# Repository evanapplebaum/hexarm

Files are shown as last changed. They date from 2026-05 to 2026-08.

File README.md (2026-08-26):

# Hexarm




A custom anthropomorphic 6-DOF leader-follower robotic arm system roughly based on the open-source [SO-100](https://github.com/TheRobotStudio/SO-ARM100) design. Built for hands-on experience in mechanical design, embedded systems, and robot teleoperation, with imitation learning via the [LeRobot](https://github.com/huggingface/lerobot) framework.

> **Status:** ✅ Core pipeline complete. Both arms were built, calibrated, and made to teleoperate end-to-end. An ACT policy trained on a 50-episode pick-and-place dataset was run autonomously on the physical follower arm via a dead-man's-switch-gated control loop. Full session-by-session history lives in [docs/context.md](docs/context.md).

---

## Demo

<p align="center">
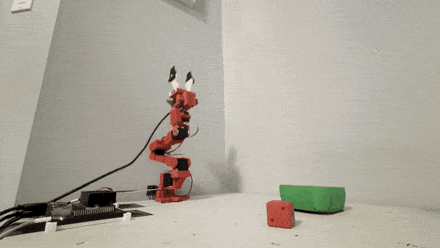
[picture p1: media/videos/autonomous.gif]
ACT policy running autonomously on the follower arm
  
</p>

**Autonomous policy.** An ACT policy trained on 50 teleoperated demonstrations, running
on the follower arm with no human input: approach, grasp, transport, release. Clip is
1.25× real time.

<p align="center">
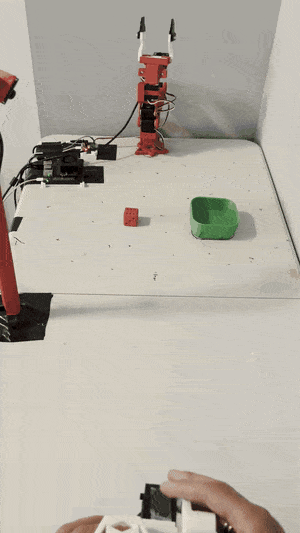
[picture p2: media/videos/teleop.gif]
Teleoperation: leader arm driven by hand, follower mirroring
  
</p>

**Teleoperation.** The leader arm (bottom) is backdriven by hand; the follower (top)
mirrors it at 50 Hz over a single half-duplex servo bus. This is how the training
demonstrations were recorded.

---

## Overview

| Property | Value |
|---|---|
| Configuration | Leader-follower (2 arms) |
| Degrees of Freedom | 6 per arm (5 + gripper) |
| Actuators | FEETECH STS3215 (6× per arm, 12 total) |
| Servo Driver | Waveshare Bus Servo Adapter (A) — half-duplex TTL, USB host |
| Compute | NVIDIA Jetson Orin Nano Super (JetPack 7.2, Ubuntu 24.04) |
| Bus interface | USB CDC-ACM on `/dev/ttyACM0` at 1 Mbps |
| Bus topology | Single bus — both arms (follower IDs 1–6, leader IDs 7–12) |
| Framework | [LeRobot](https://github.com/huggingface/lerobot) (`feetech` extra, editable install) |
| CAD Tool | [Onshape](https://cad.onshape.com) (public) |
| Reach | 433 mm |
| Payload | 1.2 kg @ worst case scenario (maximum reach) |

---

### CAD

| Leader | Follower |
|---|---|
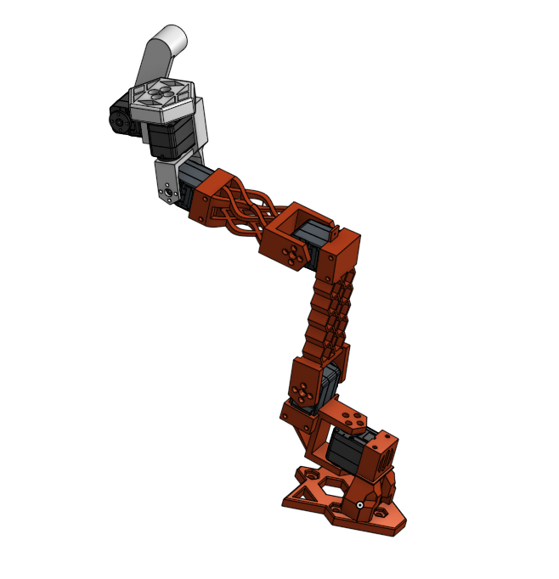
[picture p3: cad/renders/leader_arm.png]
Leader arm CAD assembly
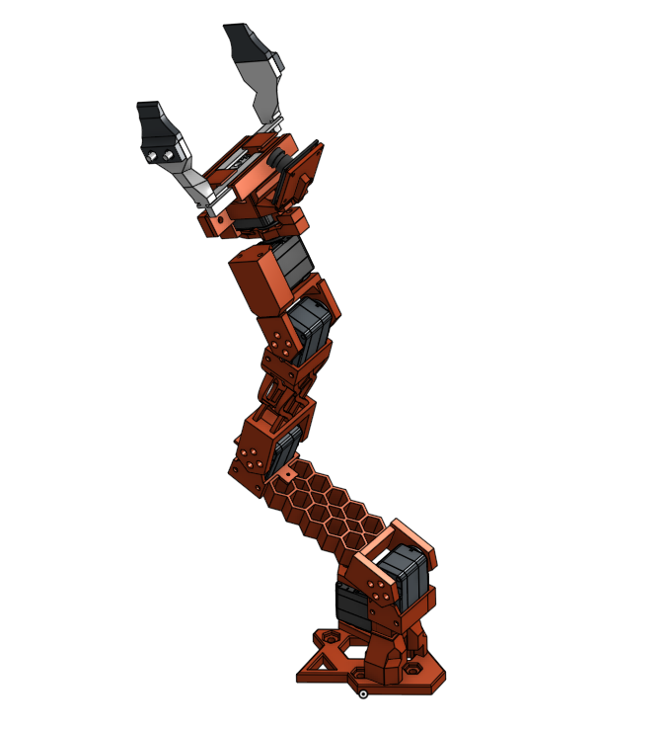
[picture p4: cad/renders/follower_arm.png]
Follower arm CAD assembly
|  |  |

*CAD renders (Onshape, 2026-08-09) of the finished leader and follower arm assemblies.*

### Hardware Photos

<table>
<tr>
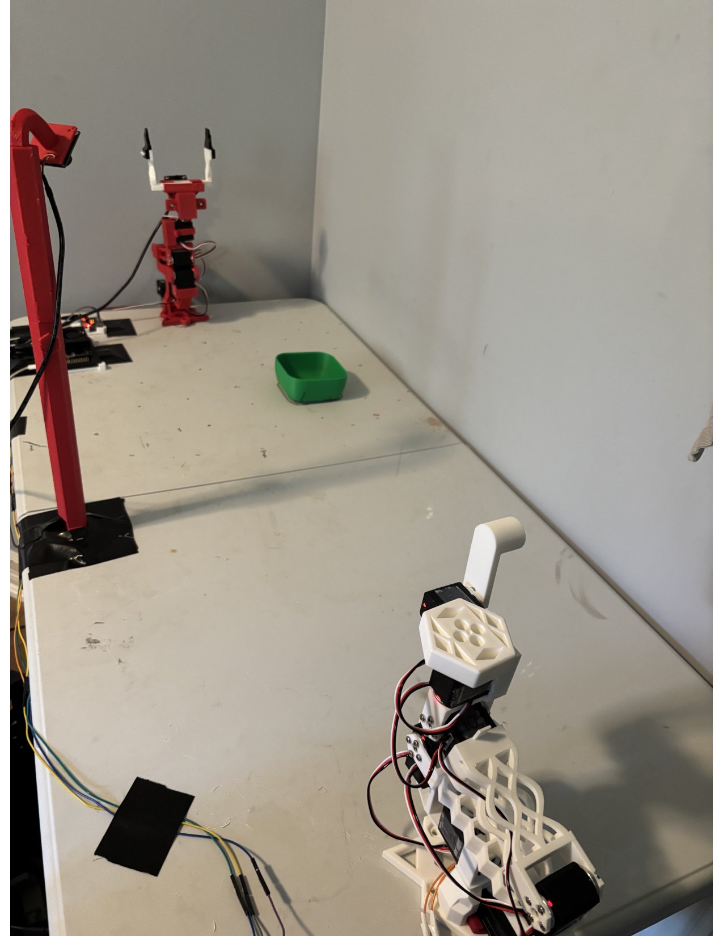
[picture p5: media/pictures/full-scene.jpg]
<td align="center"><br>Full workspace scene</td>
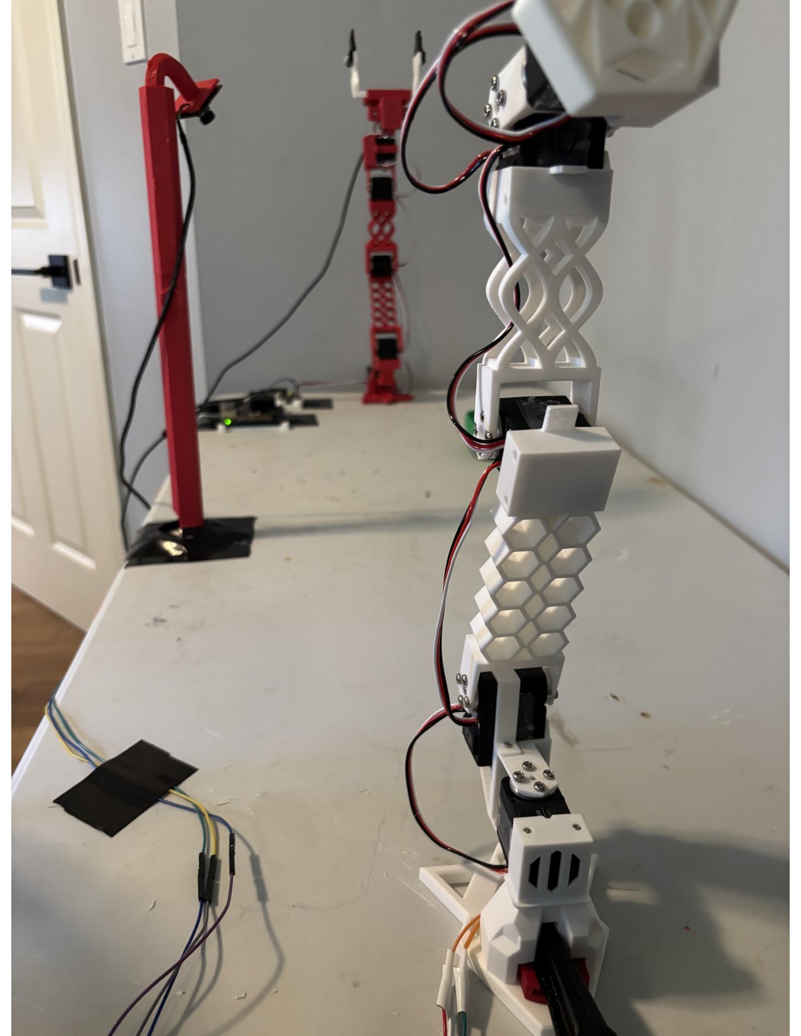
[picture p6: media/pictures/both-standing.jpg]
<td align="center"><br>Both arms</td>
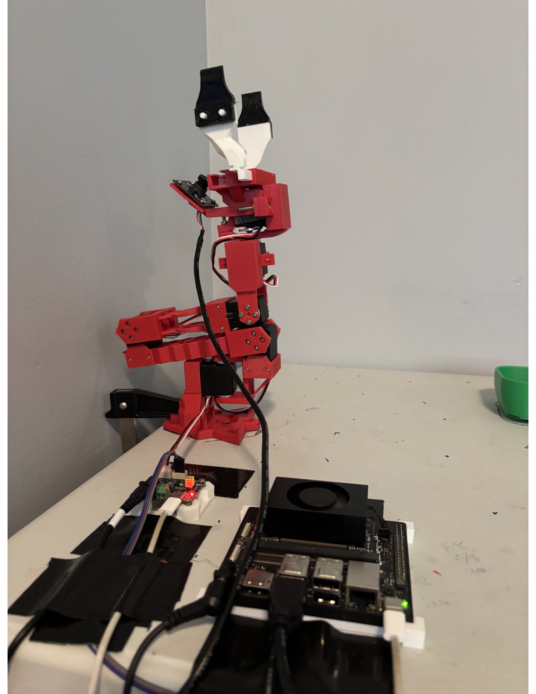
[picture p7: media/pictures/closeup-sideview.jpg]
<td align="center"><br>Side view close-up</td>
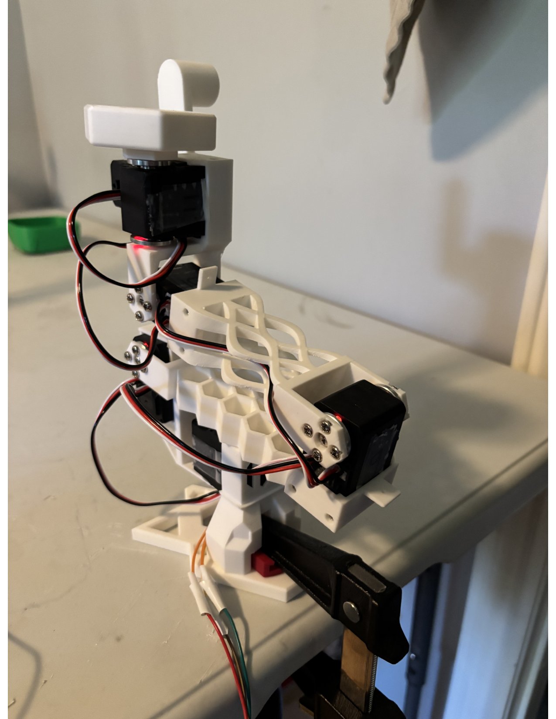
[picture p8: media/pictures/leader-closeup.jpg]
<td align="center"><br>Leader close-up</td>
</tr>
<tr>
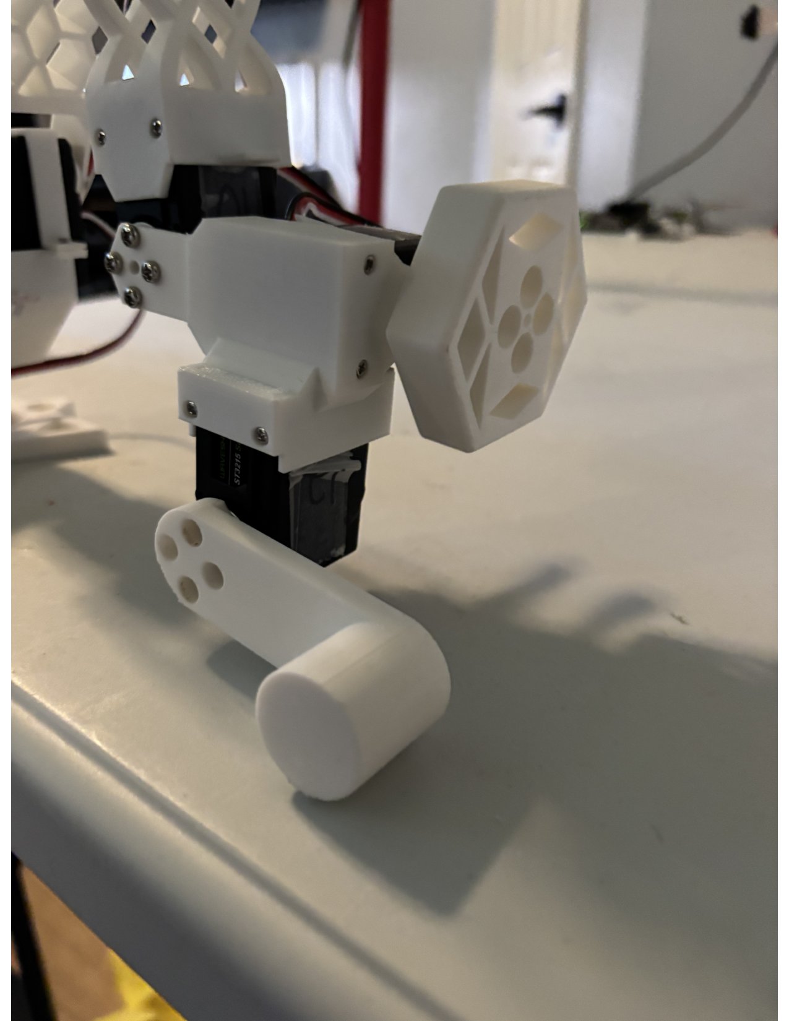
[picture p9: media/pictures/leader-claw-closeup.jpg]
<td align="center"><br>Leader claw close-up</td>
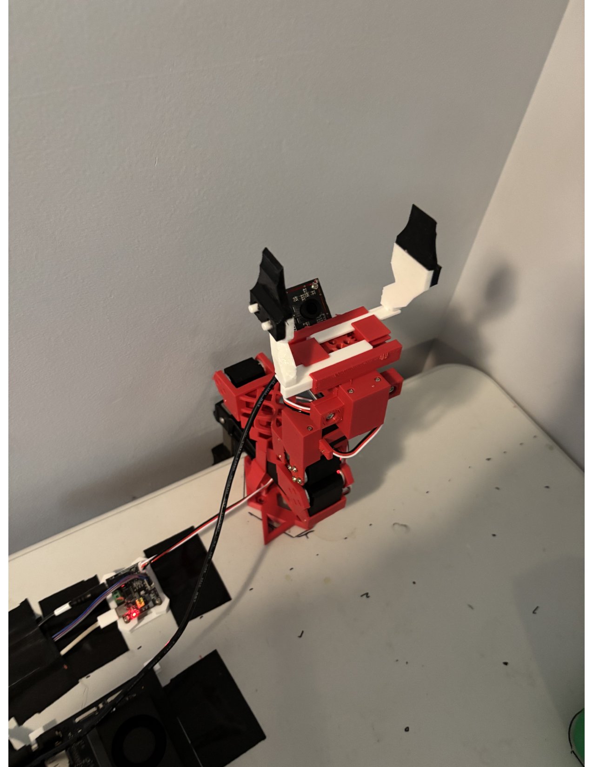
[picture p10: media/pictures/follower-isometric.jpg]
<td align="center"><br>Follower isometric</td>
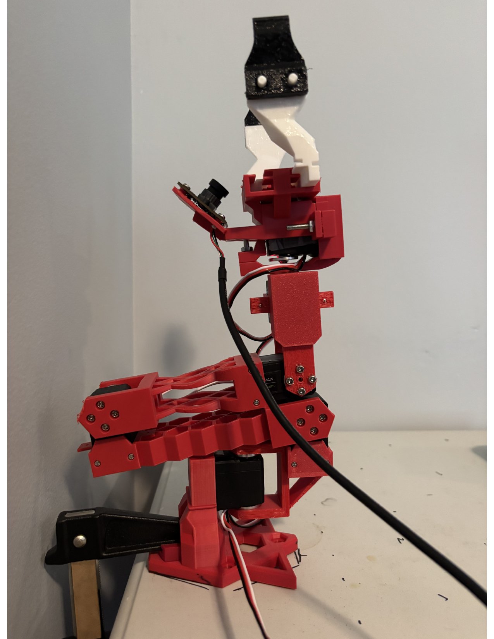
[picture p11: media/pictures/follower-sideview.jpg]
<td align="center"><br>Follower side view</td>
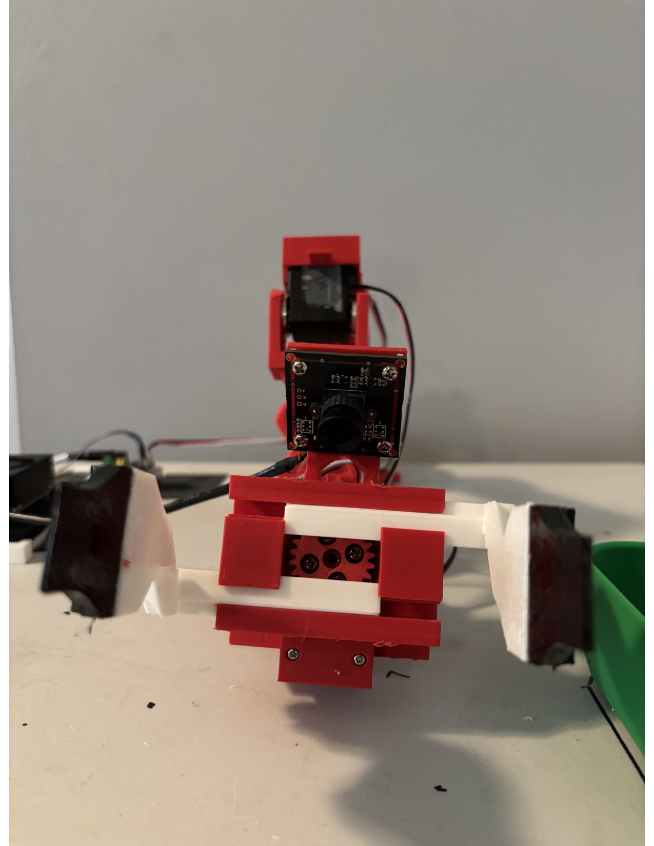
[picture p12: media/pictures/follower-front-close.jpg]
<td align="center"><br>Follower front close-up</td>
</tr>
<tr>
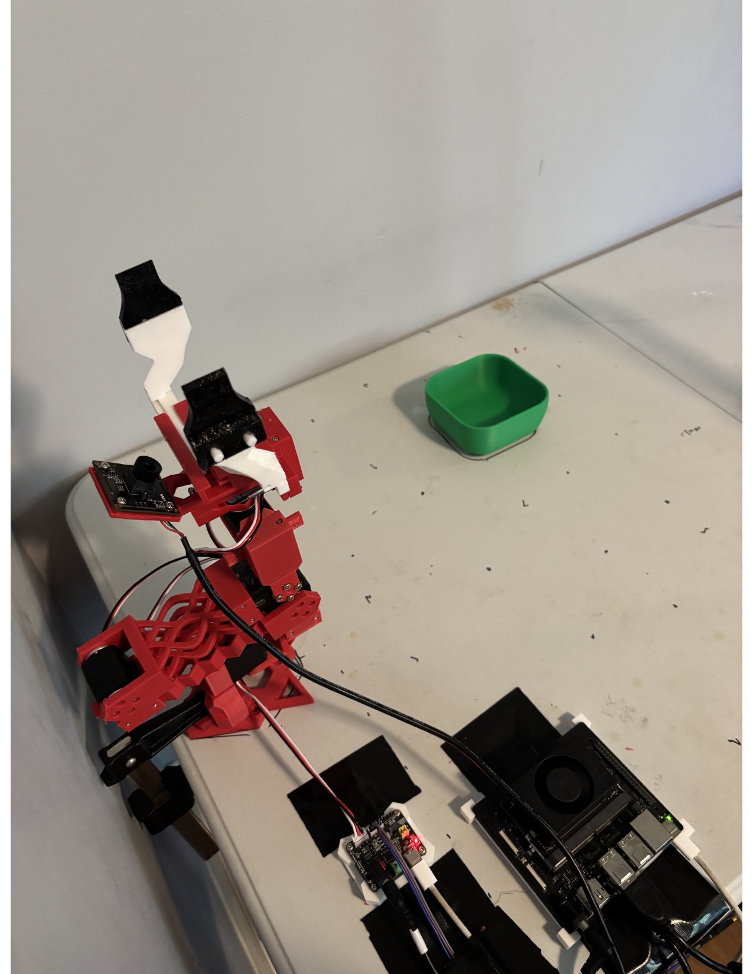
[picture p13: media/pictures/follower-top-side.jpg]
<td align="center"><br>Follower top/side view</td>
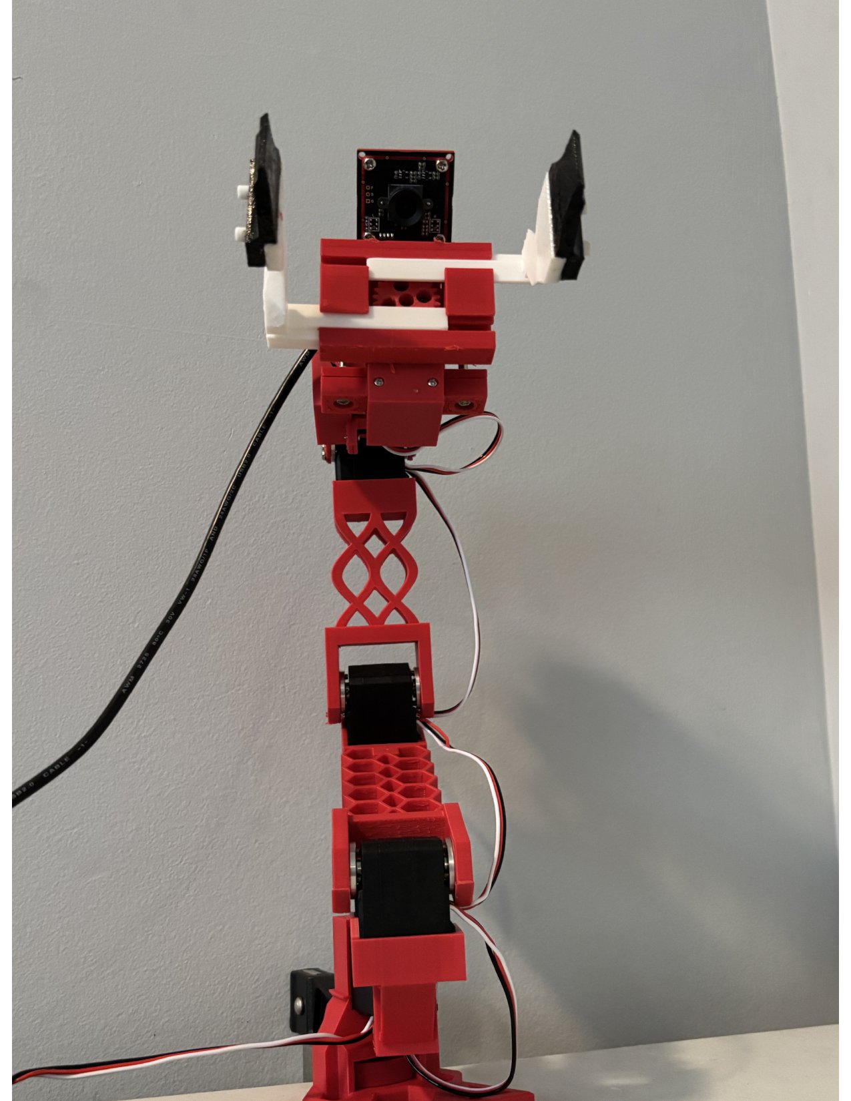
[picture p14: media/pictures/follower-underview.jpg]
<td align="center"><br>Follower underside</td>
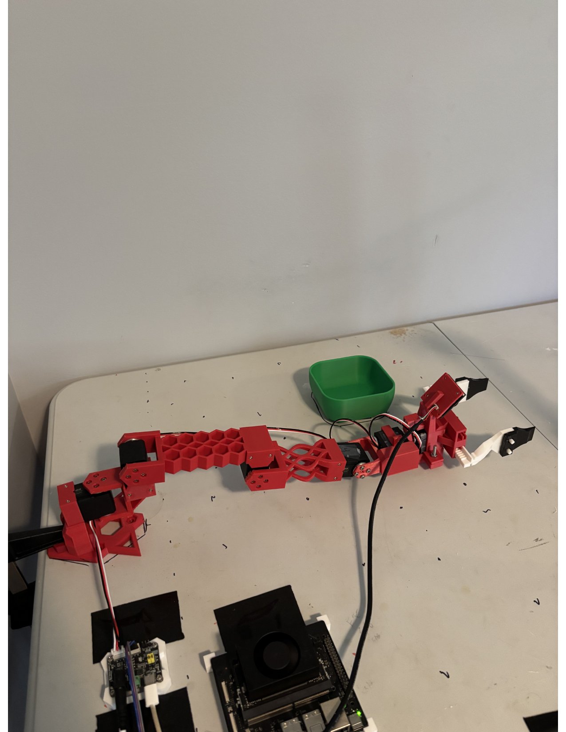
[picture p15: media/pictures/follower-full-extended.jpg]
<td align="center"><br>Follower fully extended</td>
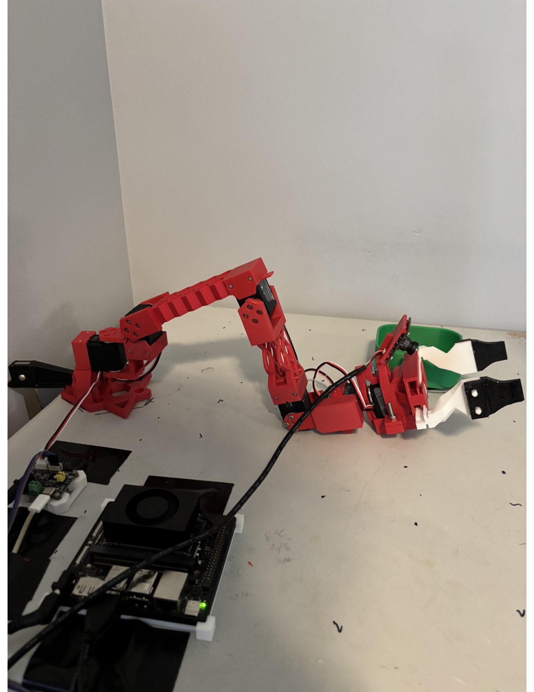
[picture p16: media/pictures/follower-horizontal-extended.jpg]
<td align="center"><br>Follower horizontal reach</td>
</tr>
<tr>
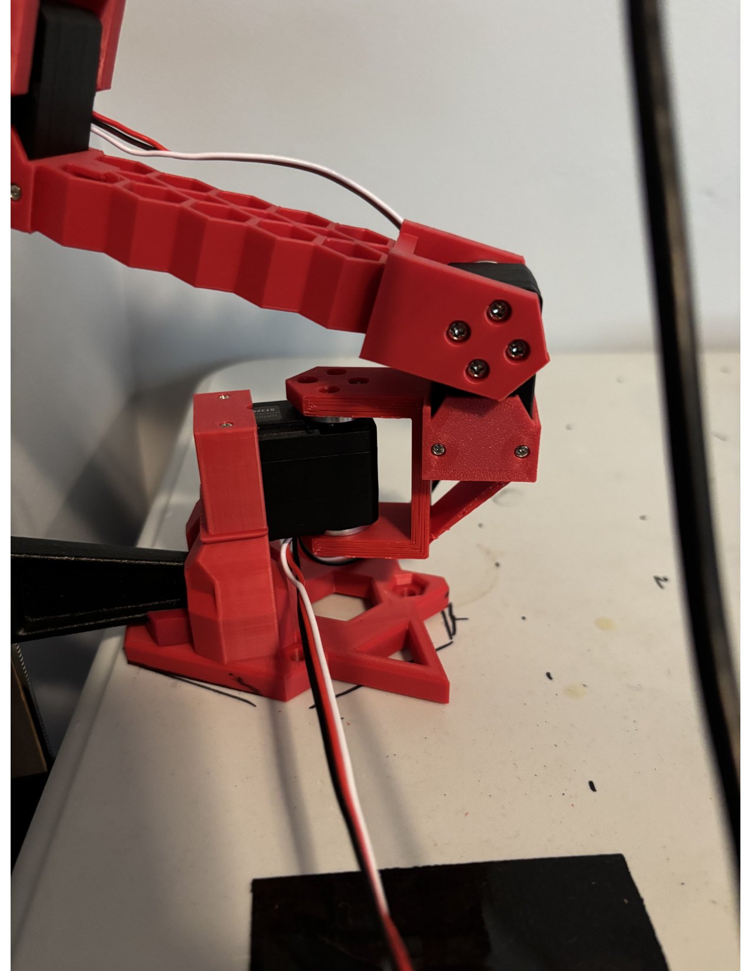
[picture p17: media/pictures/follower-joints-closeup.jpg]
<td align="center"><br>Follower joints close-up</td>
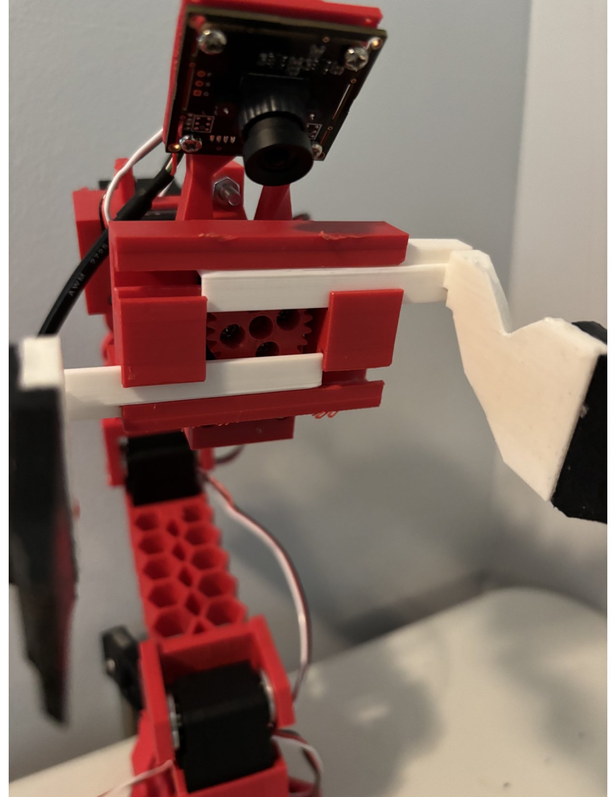
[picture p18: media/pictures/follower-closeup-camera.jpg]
<td align="center"><br>Follower wrist camera close-up</td>
</tr>
</table>

*Real hardware photos (2026-08-21) of the finished leader and follower arms.*

---

## Repository Structure

```
hexarm/
├── cad/            # Mechanical design files and exports (Onshape)
├── media/          # Hardware photos of robots & workspace (media/pictures/)
├── software/       # Control, calibration, and low-level setup scripts
└── docs/           # Technical documentation and debugging logs
```

Key entry points inside `software/`:

```
software/
├── control/teleop.py            # leader-follower teleoperation loop (working)
├── control/record_dataset.py    # records teleoperated demos into a LeRobotDataset
├── control/run_policy.py        # runs a trained checkpoint on the physical follower arm
├── calibration/                 # LeRobot-based calibration + arm control
├── vision/camera_preview.py     # headless MJPEG live-view tool for camera positioning
└── low-lvl-setup/               # raw SDK diagnostics and one-time setup tools
```

---

## Documentation

- [Hardware Assembly Guide — fastener reference, build order, workspace setup](docs/hardware-assembly-guide.md)
- [Teleop Control Loop — 50 Hz `sync_read` → `sync_write` design reference](docs/teleop-control-loop.md)
- [Servo Protocol Reference — STS3215 packet protocol + hardware-verified gotchas](docs/servo-protocol-reference.md)
- [Project Context — full hardware/software handoff](docs/context.md)
- [Postmortems — consolidated incident log (symptom → root cause → fix → lesson)](docs/debugging/postmortems.md)
- [Servo Comms Bring-Up — full UART/SDK debugging chronology](docs/debugging/servo-comms-debug-log.md)
- [CAD Assembly (Onshape, public)](https://cad.onshape.com/documents/0670dbd7fb06bb7c9bf9782d/w/e043c38067500e43503b5676/e/e17080d119308b27c44a0ee6) — full parametric model, leader and follower arms modeled separately
- ADR — [0001: compute platform selection](docs/adr/0001-compute-platform-selection.md) (Pi Zero 2W → Jetson Orin Nano Super), [0002: single-bus servo topology](docs/adr/0002-single-bus-servo-topology.md) (vs. LeRobot's two-bus default)

---

## Getting Started

### Hardware

- NVIDIA Jetson Orin Nano Super (JetPack 7.2, Ubuntu 24.04 / aarch64)
- 1× Waveshare Bus Servo Adapter (A) — set to USB-Servo mode
- 12× FEETECH STS3215 servos (both arms daisy-chained on one bus)
- 12 V DC supply for the servo bus (via the board's barrel jack) - minimum 5A
- 19 V DC supply for Jetson Orin Nano Super (comes with the Dev Kit)

### Physical Hookup / Power

| Adapter | Output | Powers | Connector |
|---|---|---|---|
| Jetson power supply | 19V, 2.37A max | Jetson Orin Nano Super | Jetson's barrel jack |
| Servo bus power supply | 12V, 5A max | Servo bus (both arms) | Waveshare board's barrel jack |

Full connection sequence:

1. Daisy-chain both arms' servo JST connectors into the **one** Waveshare Bus Servo Adapter (A) that's in use - 2 JST ports on the adapter; one per arm.
2. Confirm the board's physical mode switch is set to **USB-Servo**. 
3. Plug the 12V/5A adapter into the Waveshare board's barrel jack (servo bus power).
4. Plug the 19V/2.37A adapter into the Jetson's barrel jack (compute power).
5. Connect the Waveshare board to the Jetson via USB.
6. Power on the Jetson and SSH in (ssh username@hostname.local).

### Software Setup (Jetson)

```bash
# Clone the repo
git clone https://github.com/evanapplebaum/hexarm.git
cd hexarm

# Raw SDK diagnostics only need pyserial — use the hexarm .venv
# Note that these 'low-level' scripts were created to modify servo registers or isolate issues while debugging hardware.
# Also note that ALL STS3215 SERVOES SHIP WITH ID = 1. Attempts to ping 2 servoes with the same ID at the same time will fail (both servoes will attempt to respond simultaneously --> jumbled data)

source .venv/bin/activate
python software/low-lvl-setup/ping_one.py --id 1     # via the scservo_sdk path
python software/low-lvl-setup/raw_ping.py --id 1     # raw pyserial diagnostic
deactivate

# Anything importing LeRobot (teleop, calibration, recording) uses the
# separate lerobot-env venv (Python 3.12+, CUDA-linked torch build)
# — see requirements.txt for exact pinned versions and the Jetson-specific
# install steps (custom torch wheel + a small local LeRobot patch)
source /data/lerobot-env/bin/activate

# Run leader-follower teleoperation:
python software/control/teleop.py
```

> **Note:** LeRobot is not installable on Intel Mac (no x86_64 torch build). For Mac-side
> diagnostics, a lightweight `pyserial`-only venv drives the same `low-lvl-setup` scripts
> over the board's USB port (`/dev/cu.usbmodem*`). See [docs/context.md](docs/context.md)
> for the full per-platform setup and the servo bus bring-up procedure.

---

## Setup Status

| Task | Status |
|---|---|
| Jetson Orin Nano Super flashed (JetPack 7.2) + SSH | ✅ Done |
| Servo bus over USB (`/dev/ttyACM0`, CDC-ACM) | ✅ Done |
| Servo communication verified (raw pyserial + scservo_sdk) | ✅ Done |
| LeRobot installed on Jetson (`pip install -e ".[feetech]"`) | ✅ Done |
| Servo IDs assigned — follower 1–6, leader 7–12, single bus | ✅ Done |
| All 12 servos responding on one bus | ✅ Done |
| Per-joint calibration (both arms) | ✅ Done — clean re-calibration complete (2026-07-27); follower re-calibrated again (2026-08-03) after a broken joint was reprinted and reassembled |
| Leader-follower teleoperation (`teleop.py`) | ✅ Done (2026-06-03) |
| Encoder wrap-around fix — code rewrite | ✅ Done (2026-06-02) |
| Angle limits flashed to servo EPROM | ✅ Done (2026-07-27) |
| Cameras (wrist + overhead, 2× Arducam OV9782 global shutter) | ✅ Done — overhead mounted & locked (2026-07-31), wrist mount reprinted, installed, and placement confirmed (2026-08-05) |
| Dataset recording | ✅ Done — `hexarm/pick_and_place_v2` (2026-08-10, 50 episodes, verified + visually reviewed); superseded by `hexarm/pick_and_place_v3` (2026-08-20, 50 episodes re-recorded with wider claw opening + higher drop-off arc, see postmortem #10) |
| Policy training | ✅ Done — v2: 25,000-step ACT run (2026-08-14), best of 5 via direct eval, L1 loss 0.1742→0.0942, monotonic, no overfitting. v3: 30,000-step ACT run on the re-recorded dataset (completed 2026-08-21, ~12h07m), best checkpoint confirmed via the same direct-eval method — see `docs/context.md` session 15 log. |
| Run trained policy on hardware | ✅ Done (2026-08-21) — v3's checkpoint run on the physical follower arm via `software/control/run_policy.py` (dead-man's-switch gated, mirrors `go_neutral.py --diagnostic`); postmortem #10's margin issues confirmed fixed. |

---

## Roadmap

### M1 — CAD Complete
- [x] CAD — individual part design
- [x] CAD — full assembly
- [x] Docs — hardware assembly guide

### M2 — Platform & Architecture Decisions
- [x] ADR — compute platform selection
- [x] ADR — single-bus servo topology

### M3 — Firmware & Low-Level Comms
- [x] Servo communication over UART/USB (register read/write)
- [x] Per-servo configuration tool (ID, baud, return delay)
- [x] Joint-limit calibration tool
- [x] Docs — servo protocol reference

### M4 — Physical Build & Integration
- [x] Compute — Jetson Orin Nano Super provisioned and networked
- [x] Software — LeRobot installed and verified
- [x] Build — print and source all parts
- [x] Build — assemble both arms
- [x] Integration — servo IDs assigned, both arms on one bus

### M5 — Teleoperation & Imitation Learning
- [x] Software — leader-follower control loop (LeRobot)
- [x] Data — record demonstration dataset (2026-08-10, 50 episodes)
- [x] Training — train ACT or diffusion policy
- [x] Deploy — run policy on hardware (v3, 2026-08-21 — postmortem #10 margins confirmed fixed)
- [x] Demo — hardware photos in README (2026-08-21; video skipped by choice — recordings ran too long)

---

## License

MIT License — see [LICENSE](LICENSE)

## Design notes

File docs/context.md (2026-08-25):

# hexarm — Project Context

> **Purpose:** Full handoff document for AI sessions (Claude Cowork, Claude.ai, etc.).
> A fresh session reading this file should be able to pick up immediately with zero catch-up questions.
> Update this file at the end of every significant work session.

---

## Summary

hexarm is a custom 6-DOF leader-follower robotic arm (based on SO-100/SO-101) built for hands-on robotics learning, with imitation learning via Hugging Face LeRobot. As of 2026-08-21, the project reached completion: both arms were built, calibrated, and made to teleoperate end-to-end, and an ACT policy trained on a re-recorded 50-episode pick-and-place dataset (v3) was run autonomously on the physical follower arm, with the margin issues from an earlier run (postmortem #10) confirmed fixed.

The bulk of this document is a chronological engineering journal — most of the narrative detail and incident history lives in [Concepts Covered (Learning Log)](#concepts-covered-learning-log), read top-to-bottom in date order. The most recent entry, [v3 run on hardware — postmortem #10 confirmed fixed, project functionally complete (2026-08-21)](#v3-run-on-hardware--postmortem-10-confirmed-fixed-project-functionally-complete-2026-08-21), is the current state of the project.

### Contents

- [AI Collaboration Style](#ai-collaboration-style)
- [Learning Approach (methodology)](#learning-approach-methodology--agreed-2026-06-01)
- [Project Overview](#project-overview)
- [Hardware](#hardware)
- [Repository Structure](#repository-structure)
- [Software Stack](#software-stack)
- [STS3215 Protocol Reference](#sts3215-protocol-reference)
- [Servo Communication — RESOLVED](#servo-communication--resolved-)
- [Setup Status](#setup-status)
- [Key Technical Notes](#key-technical-notes)
- [Concepts Covered (Learning Log)](#concepts-covered-learning-log) — the session-by-session history, chronological from here to the end of the doc

---

## AI Collaboration Style

This document is read by Claude at the start of every session. Follow these rules when working with Evan on this project:

**Coding sessions — triage by whether the code carries a model.**
The deciding question for any piece of code: *"Would a robotics interviewer ask Evan to explain this on a whiteboard?"*
- **Model-bearing code** (physics, math, control logic — homing offsets, mod-4096 reasoning, IK, teleop mapping): **Evan writes it first**, predict-first (he writes the expected output/value before running), *then* Claude red-teams it. Generation before feedback. Do NOT hand Evan the answer on this code the first time — the act of deriving it IS the education.
- **Glue code** (argparse, JSON I/O, per-joint loops, file paths, plotting): Claude writes it; Evan reads and checks he can predict the output. The "quiz me, then you write" flow is correct here.
- **Earned boilerplate** (patterns Evan has already internalized): full Claude, minimal review.
- The rule: Evan earns the delegation. He may hand a task to Claude once he can *predict its output and verify it*. If he can't predict it yet, doing it by hand is the learning, not inefficiency.
- Exception: when Evan explicitly says "teach me" or the goal is conceptual learning — then switch to Socratic mode regardless of bucket.

**General teaching style:**
- One question at a time.
- Ask before explaining — let him try first.
- Tie everything back to physical meaning and real hardware behavior.

---

## Learning Approach (methodology — agreed 2026-06-01)

How Evan is approaching learning robotics, decided in a long discussion. This governs how to pace and structure work, not just how to write code.

**Goal & timeline.** Evan is 22, targeting a solid robotics job. The current proof is **for recruiters** → favor breadth-with-polish and one or two deep, defensible subsystems.  The hexarm project is the portfolio centerpiece.

**Core principle — optimize prediction-error density, not speed.** Learning is driven by prediction error (the gap between expected and actual is the signal that updates the model and tags memory). Fast-vs-slow is the wrong axis; both fail the same way when no error loop is closed (passive reading = high load, no signal; cargo-culting = working demo, no model). The danger of AI isn't that it writes syntax — it's that it skips the prediction-error loop and leaves you fluent-feeling but model-empty.

**Why robotics fits this.** Physical bugs (oscillation, current limits, the encoder seam) live in reality, can't be hand-waved, and AI can't see the hardware — so debugging forces a real causal model. This is protection against the fluency illusion.

**The operating loop (spiral / summit-then-backtrack):**
1. Build the whole pipeline fast, top-down (cargo-culting OK) → this is the map / advance organizer. *(Currently pass 1.)*
2. Log friction — every spot where reality surprised him.
3. Rank by leverage (blocks progress? recurs? core to understanding key concepts?).
4. Deep-dive the top item to first principles, **predict-first**. Only deep-dive what *bit* you — surprise + relevance is what the hippocampus prioritizes. (Calibration broke → he now owns encoders/mod-4096/sign-magnitude/normalization. He correctly did NOT deep-dive USB framing or tqdm — they didn't bite.)
5. Consolidate by writing it up (issue → ADR/doc). The writing IS the retrieval-practice learning step, not overhead. (This unifies the project's documentation/sprint goals with the learning method.)
6. Re-spiral.

**Friction log.** Evan keeps this in his Notes app (chosen for speed). It doubles as interview-prep ("tell me about a hard bug"). Per-entry fields: **Surprise** (the prediction error, logged when it fires), Guess, Reality, **Leverage** (HIGH/MED/LOW — the backtrack trigger), Status. NOT kept as a markdown file in-repo per Evan's choice 2026-06-01.

**Code-writing policy:** see the triage rule in AI Collaboration Style above (model-bearing → Evan writes first predict-first; glue → Claude writes). The deciding question is "would an interviewer make me whiteboard this?"

---

## Project Overview

**hexarm** is a custom 6-DOF serial robotic arm built by Evan Applebaum, based on the SO-100/SO-101 open-source design by TheRobotStudio. Goal: leader–follower teleoperation system with imitation learning via Hugging Face LeRobot.

GitHub: `github.com/evanapplebaum/hexarm`

---

## Hardware

### Arm Structure
- **Design basis:** SO-100 (open-source, 3D-printed frame)
- **Configuration:** Leader arm + follower arm (6 DOF each)
- **Actuators:** 12 × FEETECH STS3215 smart servos (6 per arm)
- **CAD:** Full assembly (both arms) finalized in Onshape (2026-08-09) — [public document](https://cad.onshape.com/documents/0670dbd7fb06bb7c9bf9782d/w/e043c38067500e43503b5676/e/e17080d119308b27c44a0ee6). Leader and follower are modeled as two separate arm assemblies within the doc, not a single mirrored/derived assembly. Two build lessons surfaced during assembly and were resolved — see `docs/debugging/postmortems.md` #6 (base stability) and #7 (servo-mount joint strength). STEP exports of both arms' custom parts added to `cad/exports/`, renders added to `cad/renders/` (both 2026-08-09) — see Repository Structure below for what's in/out.

### Servos — FEETECH STS3215
- **Control:** Half-duplex TTL serial bus (NOT PWM)
- **Encoder:** 12-bit absolute magnetic — no homing needed on boot
- **Feedback:** Position, temperature, voltage, current, load — all readable over bus
- **Supply voltage:** 6–12.6V (running at ~12V in current test setup)
- **Torque:** 19.5 kg·cm @ 7.4V
- **Baud rate:** Factory default = **1,000,000 bps**
- **Factory default ID:** 1 (all servos ship as ID=1)
- **Target IDs:** Follower arm 1–6, leader arm 7–12
- All servos daisy-chained on one bus per arm, addressed by unique ID
- **Status LED:** Red LED on = powered and alive; this has been confirmed in testing. Blinking red - fault (usually overcurrent from physical blockage)

### Servo Driver Board — Waveshare Bus Servo Adapter (A)
- **Current setup: ONE board carries both arms.** All 12 servos are daisy-chained on a single bus → `/dev/ttyACM0`. Follower IDs 1–6, leader IDs 7–12. A second board is on hand for a possible future two-bus split, but it is NOT in use — teleop runs single-bus (confirmed 2026-06-03).
- Sold under "UeeKKoo" brand on Amazon but arrived in Waveshare boxes;
  Amazon listing links to the official Waveshare wiki → treat as Waveshare Bus Servo Adapter (A)
- **Waveshare wiki:** https://www.waveshare.com/wiki/Bus_Servo_Adapter_(A)
- Handles half-duplex bus direction switching in hardware (host sees full-duplex serial)
- **Two host interfaces:**
  - **USB (CH340/CH343 chip):** current connection to the Jetson — enumerates as `/dev/ttyACM0` via the `cdc_acm` driver. On Mac appears as `/dev/cu.usbmodem*` — use `cu` prefix, NOT `tty`
  - **UART GPIO pins:** used during the retired Pi era (no USB needed)
- **Physical mode switch** on board: USB-Servo for the Jetson (current platform) and Mac testing; UART-Servo was used for the Pi
- **Power:** separate DC barrel jack for servo bus power (12V)
- Compatible with ST/SC series Feetech servos including STS3215
- **Official Python SDK:** scservo_sdk (see software section)

### Compute — Jetson Orin Nano Super
- **Status:** ✅ SSHable as of 2026-05-26
- **OS:** JetPack 7.2 (L4T r39.2, Ubuntu 24.04, CUDA 13.2) — reflashed 2026-08-04 from JetPack 6.2. Reason: LeRobot requires Python ≥3.12, and no cp312 CUDA torch wheel exists for JetPack 6.2 (cp310 only); cp312 CUDA torch only exists for JetPack 7.2. Reflashed via Jetson ISO (USB installer, no x86 host needed), microSD as target, NVMe (`/data`) deliberately left untouched and preserved intact. See "Jetson JP7.2 reflash" write-up below for full details.
- **Hostname:** `eka-orin`
- **Username:** `evan0h`
- **Network:** WiFi (`wlP1p1s0`) and Ethernet (`enP8p1s0` — PCIe NIC, not `eth0`) both available; Ethernet preferred for teleop/dataset transfer.
- **SSH:** `ssh evan0h@eka-orin.local` — VS Code Remote SSH confirmed working
- **Display note:** Carrier board has DisplayPort only (no HDMI). Using DP -> HDMI on rare occasions a monitor is needed to be connected directly to the Jetson
- **Post-setup plan:** Disable GUI after oem-config to reclaim ~800MB RAM; operate permanently headless
- **Connection to driver boards:** USB (USB-Servo mode on Waveshare board) — confirmed working 2026-05-26, reconfirmed post-reflash 2026-08-04
- **Serial port:** `/dev/ttyACM0` — board enumerates via the in-kernel `cdc_acm` driver (not `ch341`/`ttyUSB0` as one might expect from the CH343 chip on the board). The CH343 presents as a CDC ACM device on Jetson/Linux, so **no out-of-tree driver is needed** — this was re-verified after the JP7.2 reflash (2026-08-04): `broadcast_ping()` via LeRobot's `FeetechMotorsBus` got responses from all 12 servo IDs on `/dev/ttyACM0` with zero driver work. Stable alternative path: `/dev/serial/by-id/usb-1a86_USB_Single_Serial_<serial>-if00`.
- **dialout group:** `sudo usermod -aG dialout evan0h` — done. Note: VS Code Remote SSH caches group memberships and may not reflect changes after reconnect. Use `newgrp dialout` as workaround, or `pkill -f vscode-server` then reconnect for a clean session.
- **Python env (LeRobot):** `/data/lerobot-env` — venv on system Python 3.12 (not conda; the Jetson CUDA wheels link against system CUDA/glibc/libstdc++, and conda's bundled copies of those cause `GLIBCXX`/CUDA resolution failures). Activate: `source /data/lerobot-env/bin/activate`. Replaces the old `/data/miniconda3/envs/lerobot` conda env (left on disk, unused).
- **Python venv (raw serial diagnostics):** `/data/hexarm/.venv` — separate from the LeRobot env, only needs `pyserial`. Rule of thumb: script imports `lerobot` (`teleop.py`, `software/calibration/*`) → `/data/lerobot-env`; script only talks raw serial (`software/low-lvl-setup/*`) → `hexarm/.venv`.

### Compute — Raspberry Pi Zero 2W (RETIRED 2026-05-26 — kept as a pointer)
Replaced by the Jetson Orin Nano Super. The full Pi UART bring-up chronology — PL011 vs mini-UART, `disable-bt`, the serial-console/`getty` trap, and the straight-through Waveshare wiring — lives in [`docs/debugging/servo-comms-debug-log.md`](debugging/servo-comms-debug-log.md). **One lesson carries forward to the Jetson:** a kernel serial console or `serial-getty` sitting on the servo UART silently eats RX bytes and breaks comms — always confirm it's off on whatever port the servos use (tracked under Setup Status → "Jetson — serial console verified off").

### Vision (cameras in hand, both mounted — 2026-08-05)
- 2× Arducam OV9782 1MP Global Shutter USB Camera Board (B0385), UVC, M12 manual-focus lens, 1280×800 MJPG. Ordered 2026-07-14, arrived ~07-22. Chosen partly for reuse as the front stereo pair on a future quadruped project.
- **Lens FOV — verified 2026-07-31:** Arducam's own B0385 manual specs the lens as **70°(H)**, confirmed to be the full/total horizontal angle (standard lens-spec convention), not a half-angle. The manufacturer does NOT publish vertical or diagonal FOV. The "~47° V" figure used in earlier planning below is a derived estimate from the 1280×800 sensor aspect ratio, not a manufacturer spec — treat it as approximate where precision matters (e.g. confirming full-reach clearance).
- **Both cameras connected and enumerated.** Each UVC camera exposes 2 `/dev/videoN` nodes (capture + metadata) — overhead is `/dev/video0`, wrist is `/dev/video2`; `/dev/video1`/`/dev/video3` are the metadata-only nodes and aren't used. Confirmed via OpenCV (`cv2.VideoCapture(idx, cv2.CAP_V4L2)`) reading MJPG @ 1280×800 successfully. `v4l2-ctl` is not installed (`sudo apt install v4l-utils`, blocked by no passwordless sudo in the current session) — not needed so far since OpenCV covers format confirmation.
- **Overhead camera — mounted and confirmed good (2026-07-31).** Positioned using a live MJPEG preview tool (see `software/vision/camera_preview.py` in Repository Structure below) against the target geometry: ~50° below horizontal, ~0.38 m above table, ~0.32 m in front of workspace center, aimed at follower workspace center, slant distance ~0.5 m. Framing locked — per the collection/deployment pose-identity constraint, do not move it again without re-deriving downstream calibration.
- **Wrist camera — reprinted mount installed (2026-08-01), placement confirmed good (2026-08-05).** The redesigned mount (built around the real 70°(H) FOV, positioned close to the jaws per the close-focus placement plan, aimed down the grasp axis — see prior entry for why the first print failed) is printed, fitted, and its aim/placement verified via the live preview tool (`software/vision/camera_preview.py`) at the actual close working distance. Both cameras are now locked — no further mount changes without re-deriving downstream calibration.
- Both cameras are wired into `software/control/record_dataset.py`'s `OpenCVCamera` config for dataset recording.
- **Camera placement research (2026-07-27):** researched where the overhead camera should go using LeRobot's own docs/blog plus general imitation-learning camera-setup practice (ALOHA-style dual-arm rigs) before mounting. Key takeaways: (1) **the leader arm must not appear in frame** — an explicit LeRobot dataset-quality rule ("Leader arm should not appear" — HF's "what makes a good dataset" post), and a real constraint here specifically because both arms share one workspace; (2) **mount rigid and fixed** — no shake, never reposition between sessions, since these policies learn from raw pixel observations tied to a specific camera pose; (3) **cover the full reachable/placement workspace**, angled rather than a strict nadir shot so the gripper isn't constantly self-occluded; (4) **pair wrist + overhead intentionally, not redundantly** — wrist gives a close-up, occlusion-robust grasp view, overhead gives global spatial context; this is LeRobot's own standard example config. Sources: [LeRobot Imitation Learning docs](https://huggingface.co/docs/lerobot/il_robots), [LeRobot Datasets blog post](https://huggingface.co/blog/lerobot-datasets), general ALOHA/dual-arm teleop camera-design background.

---

## Repository Structure

```
hexarm/
├── README.md
├── LICENSE
├── requirements.txt                    ← pinned LeRobot-env deps + Jetson-specific install steps (see README's Software Setup)
├── docs/
│   ├── context.md                      ← this file (AI handoff doc)
│   ├── teleop-control-loop.md          ← teleop.py control-loop design reference
│   ├── servo-protocol-reference.md     ← STS3215 packet protocol + hardware-verified gotchas
│   ├── hardware-assembly-guide.md      ← fastener reference, build order, workspace setup
│   ├── jetson-jp7.2-local.patch        ← LeRobot pyproject.toml patch widening the torch/torchvision upper bounds for the JP7.2 cp312 wheel (see requirements.txt)
│   ├── adr/                            ← architecture decision records
│   │   ├── 0001-compute-platform-selection.md
│   │   └── 0002-single-bus-servo-topology.md
│   ├── debugging/
│   │   ├── postmortems.md              ← consolidated incident log (symptom → root cause → fix → lesson)
│   │   └── servo-comms-debug-log.md    ← full chronology of UART/SDK debugging (Phases 1–5); read before touching servo comms
│   └── component_specs/                ← datasheets and manuals
│       ├── ST3215 Communication Manual.pdf
│       ├── ST3215-general-manual.pdf
│       ├── Servo-bus-schematic.pdf
│       ├── sts3215_memory_table.xlsx
│       └── B0385_OV9782_Global_Shutter_UVC_Camera_Datasheet_19190316e78.pdf
├── media/
│   └── pictures/                       ← real hardware photos (JPG), wired into README's Demo section
├── cad/                                ← live CAD doc linked in Hardware → Arm Structure above (Onshape, cloud-hosted — no native files stored here)
│   ├── exports/                        ← STEP exports, added 2026-08-09
│   │   ├── leader/                     ← leader arm's custom-designed parts only (base, crank, link1-4, wheel)
│   │   ├── follower/                   ← follower arm's custom-designed parts only (base, claw, claw pad, link1-5, pinion, top/bottom rack)
│   │   ├── overhead camera mount/      ← overhead tower/mount custom parts
│   │   └── sts3215_servo_reference.step ← ONE copy of the vendor STS3215 servo model (same part instanced 6×/arm in Onshape; only one kept here, not 12 near-duplicates)
│   └── renders/                        ← leader_arm.png, follower_arm.png — isometric assembly screenshots, used in README Demo section (added 2026-08-09)
├── outputs/train/                      ← local lerobot-train run outputs (checkpoints), gitignored
│   ├── act_benchmark_local/            ← short local benchmark run, used to size Jetson vs. cloud training time
│   ├── act_pick_and_place_v2/          ← 25,000-step run on the original dataset — checkpoints/{005000,010000,015000,020000,025000,last}
│   └── act_pick_and_place_v3/          ← 30,000-step run on the re-recorded v3 dataset; deployed checkpoint — checkpoints/{005000,...,030000,last}
├── software/
│   ├── control/                        ← application-level scripts (run from repo root, lerobot-env)
│   │   ├── teleop.py                   ← leader-follower teleoperation; single bus, 12 motors; ✅ working (2026-06-03)
│   │   ├── record_dataset.py           ← records teleoperated demos into a LeRobotDataset (both cameras + both arms); custom recorder (not `lerobot-record`) since hexarm shares one bus/port across arms; ✅ added (2026-08-03), hardened 2026-08-10: both arms return to neutral after the final episode (not just between episodes); `image_writer_threads = 4 × len(cameras)` (LeRobot's own per-camera recommendation — too few threads was silently queuing a multi-minute backlog with no console feedback); `--resume` now passes an explicit `root=HF_LEROBOT_HOME/repo_id` (required, unlike `create()`); recording resolution (`record_sizes`) is now read from the target dataset's own feature schema instead of a fixed constant — see postmortems.md #8 for the data-loss incident this fixes; full-width on-screen banner when recording starts (visible from across the room)
│   │   ├── run_policy.py               ← runs a trained checkpoint on the physical follower arm (no leader involved); dead-man's-switch gated (hold SPACE to let predicted actions reach the servos, release freezes instantly), same convention as go_neutral.py --diagnostic; ✅ written and verified (imports, checkpoint load, feature shapes) 2026-08-14, not yet run against real hardware
│   │   └── torque_off.py               ← interactive torque disable
│   ├── vision/                         ← camera positioning/dev tools (not part of the LeRobot camera config)
│   │   └── camera_preview.py           ← headless MJPEG-over-HTTP live preview (stdlib http.server + cv2); serves one stream per --indices arg at http://<jetson-ip>:8080/videoN; used to aim/lock camera mounts before recording, then torn down
│   ├── calibration/                    ← LeRobot-based calibration and arm control scripts
│   │   ├── calibrate_lerobot.py        ← per-joint LeRobot calibration (--arm leader|follower); ✅ implements the fixed wrap-around flow (see Encoder Wrap-Around); single-Enter-per-joint flow (2026-08-01)
│   │   ├── go_neutral.py               ← move BOTH arms to the shared neutral pose (config/neutral.json); no --arm flag (2026-08-01); importable by other scripts; `at_neutral()` pre-check + `--diagnostic` hold-to-move mode (2026-08-03)
│   │   ├── record_neutral.py           ← capture the follower's pose as the shared config/neutral.json used by both arms; no --arm flag (2026-08-01)
│   │   ├── set_startup_sequence.py     ← both arms to neutral (skipped if already there) → torque off on leader only → Enter → 5s countdown → 10s recording @ 50Hz → config/startup_sequence.json; ✅ new (2026-08-01), rewritten to start from neutral (2026-08-03)
│   │   ├── run_startup_sequence.py     ← neutral → play recorded sequence on both arms → neutral; importable (used by teleop.py) or standalone; ✅ new (2026-08-01)
│   │   ├── keyboard_follower.py        ← keyboard control of follower arm (normalize=False); ✅ works
│   │   └── monitor_joints.py           ← live joint position display
│   ├── low-lvl-setup/                  ← raw SDK diagnostics and one-time setup tools
│   │   ├── _serial_utils.py            ← shared SDK helpers: open_sdk_port, retry wrappers (use these in new scripts)
│   │   ├── ping_one.py                 ← ping a single servo (CLI: --port, --id, --baud)
│   │   ├── raw_ping.py                 ← raw pyserial diagnostic, bypasses SDK entirely
│   │   ├── baud_scan.py                ← scans all baud rates × IDs 1–20 for any response
│   │   ├── setup_servo.py              ← flash ID, return delay, baud rate to one servo at a time
│   │   ├── ping_stress.py              ← stress-ping a servo N times, logs results to CSV
│   │   ├── sdk_diag.py                 ← diagnostic — runs 5 read patterns, isolates SDK vs raw-path bugs
│   │   ├── calibrate.py                ← interactive MIN/MAX/MID joint-limit calibration → config/limits.json
│   │   ├── move_one.py                 ← ping, ReadPos, torque enable, move to home.json position
│   │   ├── flash_angle_limits.py       ← write limits.json angle limits to servo EPROM
│   │   └── read_register.py            ← read arbitrary EPROM/SRAM register (raw pyserial)
│   ├── scservo_sdk/                    ← Feetech official SDK (NOT a pip package — local copy)
│   │   ├── protocol_packet_handler.py  ← packet framing/parsing — UNMODIFIED, keep upstream
│   │   ├── sms_sts.py                  ← STS/SMS series class (correct for STS3215)
│   │   ├── port_handler.py             ← stock readPort; only edit is timeout=0.1 (so VMIN works)
│   │   └── ...
│   ├── arduino/
│   │   ├── ping_servo/
│   │   │   └── ping_servo.ino          ← Arduino ping sketch (half-duplex, 1kΩ resistor wiring) - USED AS DIY SERVO DRIVER
│   │   ├── ping_servo_uno/
│   │   │   └── ping_servo_uno.ino      ← Uno variant
│   │   └── st3215-src/                 ← Feetech Arduino library source (SCServo)
│   │       └── SCServo/                ← Library with SMS_STS, SCSCL classes + examples
│   └── config/
│       ├── limits.json                 ← joint travel limits (populated by calibrate.py, leader arm)
│       ├── home.json                   ← raw encoder home positions for move_one.py (IDs 1–6)
│       ├── motion_profile.json         ← shared {velocity, acceleration} defaults for go_neutral.py/run_policy.py — one source of truth so tuning one file updates both
│       ├── calibration_follower.json   ← LeRobot calibration — follower arm (IDs 1–6); ✅ working
│       ├── calibration_leader.json     ← LeRobot calibration — leader arm (IDs 7–12); ✅ working
│       ├── neutral.json                ← single shared neutral pose, normalized 0–100, applied identically to BOTH arms (2026-08-01; replaces neutral_follower.json/neutral_leader.json — see Setup Status for why)
│       ├── neutral_follower.json, neutral_leader.json ← stale, unused — pre-unification per-arm captures, kept on disk but superseded by neutral.json
│       └── startup_sequence.json       ← recorded leader-arm motion (50 Hz, ~10s of samples), played on both arms at teleop startup; ✅ new (2026-08-01), extended from 5s (2026-08-03)
├── .venv/                              ← Python venv (recreate per platform — NOT cross-platform)
└── .gitignore
```

There is no `config.py` in the current tree — an earlier Pi-era config module (Pi 5 UART port assignments, direct-wiring resistor notes) was fully superseded by the `software/config/*.json` files above plus per-script `--port` CLI args, and was removed. `software/kinematics/`, `software/utils/`, and a top-level `simulation/urdf/` never got built — the FK/IK/URDF work they'd have held (formerly Roadmap M4) was dropped outright (2026-08-21), not just deferred, so there's no plan to add them.

---

## Software Stack

```
LeRobot policy / teleop loop        (Jetson — ARM64 + CUDA, torch works; NOT usable on Intel Mac)
        ↓
FeetechMotorsBus                    (register map abstraction)
        ↓
scservo_sdk / pyserial              (raw packet framing over UART)
        ↓
USB/UART → Waveshare board → servo bus
```

### scservo_sdk vs STservo_sdk
Both SDKs are from Feetech/Waveshare and use identical packet protocols for STS3215:
- `scservo_sdk` — Feetech's original SDK; uses class `sms_sts` for STS/SMS servos; **this is the one in use**
- `STservo_sdk` — Waveshare's renamed version; uses class `sts` (functionally identical); **deleted from repo** (Windows venv, redundant)
- "SCServo" is Feetech's brand name for the whole ecosystem, not a specific protocol
- `port_handler.py` has one minimal change vs. upstream — `setupPort()` opens pyserial with `timeout=0.1` instead of `timeout=0`. The `timeout=0` default sets `O_NONBLOCK` on the fd, which makes `ser.read()` return immediately regardless of VMIN, breaking all SDK reads. `timeout=0.1` removes `O_NONBLOCK` and lets the VMIN=1 termios setting (applied in `_serial_utils.open_sdk_port`) actually take effect.
- `readPort()` is stock — a previous custom resync layer was reverted on 2026-05-25 (see Phase 5 of `docs/debugging/servo-comms-debug-log.md`). Any per-call retry/error-recovery now lives in `software/control/_serial_utils.py`.

### Mac Development Environment
- **Venv:** `hexarm/.venv` (Python 3.12)
- **Activate:** `source .venv/bin/activate` (from hexarm root, every new session)
- **Installed packages:** pyserial 3.5
- **LeRobot:** NOT installable on Intel Mac — torch 2.7+ has no x86_64 macOS build
- **Serial port:** `/dev/cu.usbmodem5B141112771` (confirmed working port name)
  - IMPORTANT: use `cu` prefix, NOT `tty` — `tty` blocks waiting for carrier detect
  - Port shows as `usbmodem` (USB CDC) not `usbserial` (CH340 with driver)
- **SDK in use:** `scservo_sdk` (in `software/scservo_sdk/`, imported via `sys.path.insert`)

### LeRobot (Jetson — target platform)
- Feetech driver: `lerobot.motors.feetech.feetech.FeetechMotorsBus`
- Python 3.12 required (LeRobot main branch requires >=3.12)
- **Conda env:** `lerobot` (Python 3.12) at `/data/miniconda3/envs/lerobot/` — activate: `conda activate lerobot`
- **PyTorch:** installed from PyPI cu126 index (`https://download.pytorch.org/whl/cu126`) — torch 2.x, CUDA 12.6 compatible
- **Repo:** cloned at `/data/lerobot`, installed with `pip install -e ".[feetech]"` — ✅ confirmed working 2026-05-31
- **NVMe SSD:** 512GB mounted at `/data` — all LeRobot data, conda env, and repo live here
- **Servo ID convention (UPDATED):** Both arms on ONE bus (/dev/ttyACM0), one driver board. Follower IDs 1–6, leader IDs 7–12. LeRobot's two-bus assumption does NOT apply.
- **Scripts live in hexarm repo** (`software/control/`), import from lerobot conda env. Run from hexarm root with `conda activate lerobot`.

### FeetechMotorsBus API (confirmed 2026-05-31)
```python
from lerobot.motors.feetech import FeetechMotorsBus
from lerobot.motors.motors_bus import Motor, MotorCalibration, MotorNormMode

# Construction
bus = FeetechMotorsBus(
    port="/dev/ttyACM0",
    motors={"shoulder_pan": Motor(id=1, model="sts3215", norm_mode=MotorNormMode.RANGE_0_100), ...},
    calibration=None,   # optional: dict[str, MotorCalibration]
    protocol_version=0  # 0 = Feetech, 1 = Dynamixel
)

# Key methods
bus.connect() / bus.disconnect()
bus.enable_torque(motors=None)   # None = all motors
bus.disable_torque(motors=None)
bus.read(data_name, motor, *, normalize=True, num_retry=0) -> Value         # single motor
bus.write(data_name, motor, value, *, normalize=True, num_retry=0)          # single motor
bus.sync_read(data_name, motors=None, *, normalize=True) -> dict[str, Value]
bus.sync_write(data_name, values, *, normalize=True)
bus.set_half_turn_homings(motors=None) -> dict[NameOrID, Value]  # resets cal, reads pos, writes Homing_Offset = 2047 - present_pos
bus.record_ranges_of_motion(motors=None, display_values=True) -> tuple[dict, dict]  # (mins, maxes); waits for Enter
bus.write_calibration(calibration_dict, cache=True)  # writes Homing_Offset + Min/Max_Position_Limit to EPROM
bus.read_calibration() -> dict[str, MotorCalibration]

# MotorCalibration
MotorCalibration(id, drive_mode, homing_offset, range_min, range_max)

# MotorNormMode options
MotorNormMode.RANGE_0_100    # 0–100%
MotorNormMode.RANGE_M100_100 # –100 to +100
MotorNormMode.DEGREES        # actual degrees
```

**IMPORTANT — normalize=False behaviour (CORRECTED 2026-06-01):** The earlier belief that "homing offset doesn't affect `normalize=False` reads" was WRONG. The STS3215 applies the homing offset *in hardware*: `Present_Position = (raw_encoder − Homing_Offset) mod 4096`, reported in 0–4095. So `normalize=False` reads DO reflect the offset, and the result is always wrapped into the single-turn range. This mod-4096 behaviour requires the Phase register bit 4 (0x10) to be cleared — `bus.configure_motors()` does this for sts3215. See the Encoder Wrap-Around section for why this is the whole key to calibration.

**IMPORTANT — safe torque enable:** Always write `Goal_Position = Present_Position` for all motors before calling `enable_torque()`. Otherwise servos snap to stale goal from a previous run. See `safe_enable_torque()` helper in `calibrate_lerobot.py`.

**IMPORTANT — stale EPROM offsets:** `write_calibration` and `set_half_turn_homings` write to servo EPROM. A crashed calibration run leaves stale homing offsets in hardware. Always clear with `bus.write("Homing_Offset", name, 0, normalize=False)` before starting a new calibration.

**IMPORTANT — `num_retry` defaults to 0:** `bus.read()`/`bus.write()` do not retry a dropped status packet by default — a single missed byte on the wire raises `ConnectionError` and crashes the whole script (hit 2026-08-10 mid-`safe_enable_torque()`). LeRobot's own internal cleanup code (`disable_torque()`) uses `num_retry=5` for exactly this reason. Pass `num_retry=3` (or similar) on any `bus.read`/`bus.write` call in a script meant to run unattended — applied across `go_neutral.py`, `teleop.py`, `calibrate_lerobot.py`, `monitor_joints.py`, and `run_startup_sequence.py` (2026-08-10).

---

## STS3215 Protocol Reference

Packet format: `0xFF 0xFF | ID | LEN | INST | PARAMS... | CHECKSUM`
- Checksum = `~(ID + LEN + INST + PARAMS) & 0xFF`
- LEN = number of bytes after LEN field (INST + PARAMS + CHECKSUM)

Key instructions:
| Instruction | Code | Notes |
|---|---|---|
| PING | 0x01 | Servo responds with status packet |
| READ | 0x02 | Read N bytes from address |
| WRITE | 0x03 | Write to address |
| SYNC_WRITE | 0x83 | Broadcast write to multiple servos |

Key register addresses (sms_sts / STS3215):
| Register | Address | Notes |
|---|---|---|
| ID | 5 | EPROM — requires lock/unlock |
| BAUD_RATE | 6 | EPROM — 0=1Mbps, 1=500K, etc. |
| TORQUE_ENABLE | 40 | SRAM — 1=enabled |
| GOAL_POSITION_L/H | 42–43 | SRAM — 0–4095 range |
| PRESENT_POSITION_L/H | 56–57 | SRAM — read only |

Broadcast ID = 0xFE (254) — no response expected, servo acts but does not reply.

---

## Servo Communication — RESOLVED ✅

End-to-end SDK path has worked since 2026-05-25 (on the Pi) and now runs on the Jetson over `/dev/ttyACM0`. The bring-up took three stacked root causes to untangle; the full chronology (Phases 1–5) lives in [`docs/debugging/servo-comms-debug-log.md`](debugging/servo-comms-debug-log.md). Condensed:

1. **No response — wrong wiring.** The Waveshare board uses **straight-through** wiring (TX→TX, RX→RX), not crossed; it labels pins from the host's perspective.
2. **Intermittent "framing errors" — misdiagnosis.** A custom resync parser added to `port_handler.readPort()` was based on a self-consistent but wrong theory; it was reverted. Kept in the debug log as a cautionary tale about falsification testing.
3. **The real cause — serial console + SDK byte-stealing.** A kernel serial console / `serial-getty` on the servo UART silently ate RX bytes, and the resync layer's `length+1` read stole a byte from `ping()`'s second transaction (`COMM_RX_CORRUPT`).

**Fixes that still apply on any platform (Jetson included):**
- Ensure no serial console / `getty` owns the servo port (`/proc/cmdline`, `systemctl is-enabled serial-getty@<port>`).
- `port_handler.setupPort()` opens pyserial with `timeout=0.1` (not `timeout=0`, which sets `O_NONBLOCK` and defeats VMIN).
- `_serial_utils.set_vmin(ser, vmin=1)` so `ser.read(1)` inside the SDK actually blocks.
- `readPort()` is stock upstream; retry/recovery lives in the `_serial_utils` wrappers (`ping_with_retry`, etc.) — the correct scope.

**STS3215 reports model number 777** from `ping()` — a quick health check. See debug log Phase 5 for the full root-cause analysis.

---

## Setup Status

| Task | Status |
|---|---|
| **CAD / Mechanical** | |
| CAD — individual part design | ✅ Done |
| CAD — full assembly (both arms, leader + follower) | ✅ Done (2026-08-09) — [Onshape doc](https://cad.onshape.com/documents/0670dbd7fb06bb7c9bf9782d/w/e043c38067500e43503b5676/e/e17080d119308b27c44a0ee6). STEP exports of custom parts in `cad/exports/` (2026-08-09). Renders pending. |
| Docs — hardware assembly guide | ⏳ Todo |
| **Compute** | |
| Jetson Orin Nano Super — JetPack 6.2 flash | ✅ Done (2026-05-26), superseded — see JP7.2 reflash below |
| Jetson Orin Nano Super — JetPack 7.2 reflash (R39.2, Ubuntu 24.04, CUDA 13.2) | ✅ Done (2026-08-04) — via Jetson ISO, microSD target, NVMe/`/data` preserved untouched. Reason: LeRobot needs Python ≥3.12; only JP7.2 has cp312 CUDA torch wheels for Jetson. Full write-up below. |
| Jetson — oem-config first-boot wizard | ✅ Done |
| Jetson — SSH access configured | ✅ Done (`ssh evan0h@eka-orin.local`) |
| Jetson — GUI disabled (headless mode) | ⏳ Todo |
| Jetson — UART device nodes confirmed for servo chains | ✅ Done (/dev/ttyACM0 via cdc_acm; reconfirmed post-JP7.2-reflash 2026-08-04, no driver work needed) |
| Jetson — serial console verified off UART used for servos | ⏳ Todo |
| NVMe SSD (512GB) mounted at /data | ✅ Done (2026-05-28, ext4, fstab entry added); survived JP7.2 reflash intact (2026-08-04) |
| **Software** | |
| Mac venv created (Python 3.12) | ✅ Done |
| pyserial installed in Mac venv | ✅ Done |
| scservo_sdk copied into software/ | ✅ Done |
| ping_one.py, raw_ping.py, baud_scan.py, setup_servo.py created | ✅ Done |
| _serial_utils.py (shared SDK helpers + retry wrappers) | ✅ Done (2026-05-25) |
| sdk_diag.py (read-pattern diagnostic) | ✅ Done (2026-05-25) |
| port_handler.py reverted to upstream readPort | ✅ Done (2026-05-25) |
| LeRobot conda env (Python 3.12) on Jetson | ⚠️ Superseded (2026-08-04) — replaced by `/data/lerobot-env` venv (system Python 3.12) after the JP7.2 reflash; old conda env left on disk unused |
| PyTorch installed (cu126, Jetson) | ⚠️ Superseded (2026-08-04) — replaced by torch 2.12.0 (cp312, CUDA 13.2) from Shattered217/Jetson-Orin-Wheels; `torch.cuda.is_available()` verified `True` |
| LeRobot pip install -e ".[feetech]" | ✅ Done (2026-05-31); reinstalled into `/data/lerobot-env` post-reflash (2026-08-04), lerobot 0.6.1 |
| LeRobot installed in Mac venv | ❌ Not possible (Intel Mac) |
| **Hardware / Servos** | |
| Mac → board → servo communication working | ⚠️ Not yet tested (USB-Servo mode) |
| Jetson → board → servo communication working | ✅ Done (2026-05-26, USB, /dev/ttyACM0) |
| Driver board UART wiring to Jetson | ✅ Done (USB-Servo mode, ttyACM0 via cdc_acm driver) |
| Servo IDs assigned — follower 1–6, leader 7–12, single bus | ✅ Done — both arms on /dev/ttyACM0; see LeRobot section for ID convention |
| Bus communication test (all 12 servos) | ✅ Done (2026-06-03, both arms responding, teleop confirmed) |
| SDK path (ping_one, calibrate) working on Jetson | ✅ Done (2026-05-26, sdk_diag 5/5, ping_one confirmed) |
| Angle limits flashed to servo EPROM | ✅ Done (2026-07-27) |
| Cameras — 2× Arducam OV9782 (B0385) global shutter USB, wrist + overhead | ✅ In hand, both connected (`/dev/video0` overhead, `/dev/video2` wrist). See Vision section above. |
| Local git object DB — corrupted loose objects found | ✅ Fixed (2026-08-03) — found 2026-07-31, 6 empty/corrupt loose objects (`master`'s tip commit among them). Packed history and `origin` were unaffected, so the fix was: delete the corrupt loose objects and the two local refs pointing at the corrupt commit, then `git fetch origin` to redownload it (refs already claiming to "have" a commit block fetch from resending it, so they had to go first). `git fsck --full` clean after. The 2026-08-01 session's uncommitted script changes were then committed (`60ce4ac`) and pushed. |
| **Application** | |
| config.py rewrite (Jetson ports, remove Pi 5 / Pi Zero 2W refs) | ✅ Obsolete — `config.py` was removed entirely, superseded by `software/config/*.json` + per-script `--port` CLI args (no Pi-era references remain to clean up) |
| move_one.py — ping, ReadPos, torque enable, home move | ✅ Done (2026-05-28) |
| torque_off.py — interactive torque disable | ✅ Done (2026-05-28) |
| flash_angle_limits.py — write limits.json to servo EPROM | ✅ Done (2026-05-28) |
| keyboard_follower.py — LeRobot keyboard control of follower arm | ✅ Done (2026-05-31) |
| calibrate_lerobot.py — per-joint LeRobot calibration, both arms | ✅ Done — rewritten around configure_motors()/set_half_turn_homings()/record_ranges_of_motion() (2026-06-02). Clean re-calibration with current arms completed 2026-07-27. Redundant mid-flow Enter prompt removed 2026-08-01 — now one Enter to home+start the sweep, one Enter to record and advance (see Neutral Pose Unification section). |
| LeRobot calibration — encoder wrap-around fix | ✅ Done (solved 2026-06-01, code rewritten 2026-06-02) |
| go_neutral.py — move both arms to shared neutral; importable | ✅ Done — rewritten 2026-08-01: `--arm` flag removed, always drives both arms to the one shared `neutral.json` (previously per-arm `--arm follower\|leader\|both`). Extended 2026-08-03: `at_neutral()` helper (checks whether all joints are already within tolerance without commanding motion — lets callers skip the move entirely), `--diagnostic` dead-man's-switch mode (hold SPACE to move, release freezes in place via `Goal_Position = Present_Position`, 'q' aborts — no key-up event over a raw SSH terminal, so "held" is inferred from OS keyboard auto-repeat within a 0.2s window), and the arrival-tolerance comparison fixed from strict `<` to `<=` (a joint sitting exactly on the tolerance boundary never registered as arrived, causing an apparent hang to the full timeout — see Concepts Covered). `POSITION_TOLERANCE` widened 0.5 → 1.0 normalized units. |
| record_neutral.py — capture shared neutral pose | ✅ Done — rewritten 2026-08-01: `--arm` flag removed, always hand-poses the follower only and writes the single `neutral.json` used by both arms (previously separate `neutral_follower.json`/`neutral_leader.json` captures — those two files are now stale/unused on disk) |
| set_startup_sequence.py — record leader-arm startup sequence | ✅ Done (2026-08-01, software/calibration/set_startup_sequence.py). Rewritten 2026-08-03: now builds both arms on one bus, drives both to the shared neutral first (via `at_neutral()` + `go_neutral()`, skipping the move if already close), then disables torque on the leader only — the follower stays enabled and holds neutral through recording. Recording window extended 5s → 10s. Output JSON format unchanged (unprefixed joint names), so `run_startup_sequence.py` needed no changes. |
| run_startup_sequence.py — neutral → sequence → neutral, both arms | ✅ Done (2026-08-01, software/calibration/run_startup_sequence.py); used by teleop.py startup |
| teleop.py — leader-follower teleoperation | ✅ Done (2026-06-03, software/control/teleop.py). Startup rewritten 2026-08-01 to go through run_startup_sequence.py instead of a bare go_neutral() call — see Neutral Pose Unification section below for the bug this fixes. New prerequisite: `config/startup_sequence.json` must exist (run set_startup_sequence.py first) or teleop.py raises FileNotFoundError. |
| First teleoperation test | ✅ Done (2026-06-03, confirmed working perfectly) |
| .gitignore for CSV stress-test artifacts | ✅ Done — `ping_stress_*.csv` and `software/low-lvl-setup/*.csv` patterns present |
| camera_preview.py — headless MJPEG live-view tool for camera positioning | ✅ Done (2026-07-31, software/vision/camera_preview.py) |
| Overhead camera mounted at target geometry | ✅ Done (2026-07-31) — confirmed via live preview, framing locked |
| Wrist camera mounted at target geometry | ✅ Done (2026-08-05) — reprinted mount (designed around the real 70°(H) FOV) installed 2026-08-01, placement/aim confirmed via `camera_preview.py` |
| Cameras wired into LeRobot camera config | ✅ Done — both cameras wired in via `OpenCVCamera` in `software/control/record_dataset.py` |
| Dataset recording | ✅ Done (2026-08-10) — 50/50 episodes, `hexarm/pick_and_place_v2` (640×400 @ 30fps, ~28.3k frames), verified consistent across `info.json`/data/video/episode-metadata and visually reviewed via a generated thumbnail-grid QA page. A resolution-mismatch bug during recording cost 2 unrecoverable episodes from the original `hexarm/pick_and_place` dataset (3 valid episodes remain there, retired in favor of `_v2`) — see postmortems.md #8. |
| Policy training | ✅ Done (2026-08-14) — a local `lerobot-train` benchmark hard-froze the Jetson twice before being root-caused (RAM exhaustion, no swap) and fixed via zram (postmortems.md #9). Real 25,000-step run then completed locally overnight in ~6h12m (18:24→00:36) with zero issues — `tmux`-protected against SSH drops, verified via `uptime`/checkpoint timestamps that no reboot occurred. 5 checkpoints saved (5k/10k/15k/20k/25k). |
| Checkpoint evaluation | ✅ Done (2026-08-14) — no training-loss log survived (wandb disabled, tmux scrollback rolled past 6h of history), so wrote a standalone eval script loading each checkpoint and running 50 forward-pass-only batches against the training set. L1 loss: 0.1742 (5k) → 0.1354 (10k) → 0.1124 (15k) → 0.1067 (20k) → **0.0942 (25k)** — clean monotonic improvement, no overfitting; final checkpoint confirmed best of the 5. |
| Run trained policy on hardware | ✅ Done (2026-08-21) — v3 checkpoint run on the physical follower arm via `run_policy.py`, 3 successful pick-and-place completions. Postmortem #10's grazing/near-clipping margins confirmed fixed. Some runs still missed the pick due to camera-coverage blind spots — a known limitation, not a margin issue; no further training planned. See session-16 log entry below. |

---

## Key Technical Notes

### Half-Duplex Direction Switching
STS3215 uses half-duplex UART — TX and RX share one wire on the servo side. The Waveshare board handles direction switching internally. The host sends normal full-duplex serial; the board drives the bus on TX and listens on RX. There is NO echo of TX bytes back to the host's RX buffer (confirmed by comparing with official SDK, which has no echo-consuming code).

### tty vs cu on macOS
On macOS, each USB serial device appears twice: `/dev/tty.*` and `/dev/cu.*`.
- `tty` waits for carrier detect — designed for incoming connections (modems receiving calls)
- `cu` (call-up) initiates connections — correct for outbound serial communication
- Always use `/dev/cu.usbmodem*` for this board on Mac.

### Pi UART Configuration Commands (retired)

The Pi-era UART boot setup (`dtoverlay=disable-bt`, `enable_uart=1`, PL011 vs mini-UART, `cat /proc/cmdline`) is no longer used — the Jetson connects over USB. Commands and explanation are preserved in [`docs/debugging/servo-comms-debug-log.md`](debugging/servo-comms-debug-log.md). The one check that still matters on the Jetson: `cat /proc/cmdline` and `systemctl is-enabled serial-getty@<port>` to confirm nothing else owns the servo port.

### Jetson SSH Quick Reference

```bash
ssh evan0h@eka-orin.local    # mDNS hostname
ssh evan0h@<jetson-ip>       # direct IP (faster, more reliable — IP TBD)

# If SSH fails with "REMOTE HOST IDENTIFICATION HAS CHANGED" (happens after reflash):
ssh-keygen -R eka-orin.local  # removes stale host key from ~/.ssh/known_hosts
# Then retry ssh normally.
```

### scservo_sdk Import Path
The raw-SDK diagnostic scripts in `software/low-lvl-setup/` use:
```python
sys.path.insert(0, os.path.join(os.path.dirname(__file__), ".."))
from scservo_sdk import PortHandler, sms_sts, COMM_SUCCESS
```
This resolves to `software/scservo_sdk/`. These scripts run standalone (not under the LeRobot conda env), so the local SDK copy is intended here. **Do NOT** use this pattern from scripts that import LeRobot — adding `software/` to `sys.path` shadows the pip-installed `scservo_sdk` (see the teleop import-path gotcha below). Run from hexarm root or from `software/low-lvl-setup/`.

---

## Concepts Covered (Learning Log)

- SO-100 hardware architecture and design tradeoffs
- FEETECH STS3215 servo internals (encoder, bus protocol, packet framing)
- Half-duplex UART — direction control, timing, bus arbitration, echo problem
- STS3215 packet format — header, ID, length, instruction, checksum
- scservo_sdk architecture — 4 layers (def → port_handler → protocol_packet_handler → sms_sts)
- Python venv — isolation model, activation, per-session requirement
- macOS serial ports — tty vs cu distinction, usbmodem vs usbserial
- LeRobot imitation learning pipeline (teleoperation → record → train → deploy)
- Forward kinematics and DH parameters
- Jacobian matrix — physical meaning, column interpretation
- Singularities — rank deficiency, physical causes
- Pseudoinverse (J⁺) and null space
- Device Tree and overlays — how Linux embedded systems describe hardware at boot
- Pi UART architecture — PL011 vs mini-UART, why PL011 is required for 1Mbps servo comms
- Raspberry Pi SSH setup — mDNS, host key management, direct IP fallback
- UART framing errors — what "corrupting a start bit" means on a µs scale (RC transient, PL011 error flag)
- Linux tty IGNPAR — silent byte discard on framing errors, no userspace notification
- VMIN/VTIME POSIX terminal settings — how they control read() blocking, pyserial persistence bug
- `O_NONBLOCK` override of VMIN — why `pyserial(timeout=0)` defeats termios VMIN settings, and how `timeout=0.1` fixes it
- Linux serial console + `serial-getty@ttyAMA0.service` — how a console on the same UART silently breaks user-space communication (eats RX bytes, writes prompt to TX, holds baud at 115200). Always check `cat /proc/cmdline` and `systemctl is-enabled serial-getty@ttyAMA0.service` before anything else when a Pi UART misbehaves.
- Pi GPIO TX↔RX loopback testing — cheapest UART sanity check, falsifies all higher-level theories at once
- Falsifying experiments vs. self-consistent theory — Phase 4's framing-error story matched every symptom but was wrong; the loopback test collapsed it in one command
- Resync parser design — using checksum as integrity check to recover from a dropped header byte (the Phase 4 implementation; not currently in use)
- The byte-stealing pitfall — reading N+1 bytes and returning N silently steals data from the next read; breaks multi-transaction SDK calls like `ping()` (which does PING + read-model)
- STS3215 model number reported via `ping()` = **777**
- STS3215 single-turn position reporting — `Present_Position = (raw − Homing_Offset) mod 4096`; Phase register bit 4 (0x10) must be cleared (via `configure_motors()`) to enable it
- Encoder seam relocation — the 4095↔0 jump is NOT fixed to the magnet zero; it sits where `raw = Homing_Offset`, so choosing the offset moves the seam
- Home-at-center calibration — homing at the arc midpoint parks the seam 2048 counts away, i.e. in the center of the dead gap, so travel < 360° never crosses it (this is how LeRobot/SO-100 "handle" wrap joints — by avoidance, not special-casing)
- LeRobot `drive_mode` — software sign-flip applied after normalization (leader/follower direction agreement); does NOT affect encoder, offset, or seam
- LeRobot calibration internals — `_normalize`/`_unnormalize` only read range_min/max (no sign constraint); only `_serialize_data` rejects negative values, and only for the unsigned Min/Max_Position_Limit EPROM registers
- Sign-magnitude encoding — Homing_Offset uses bit 11 as sign (per Feetech tables), so negative offsets ARE writable to EPROM; position limits are unsigned
- STS3215 EPROM write workflow — unLockEprom → write → LockEprom, broadcast --force mode
- Baud rate register (reg 6) and BAUD_MAP — value encoding, power-cycle requirement
- Return delay register (reg 7) — what it does (silence before response) and what it doesn't fix (framing errors)
- git rm vs rm — staging deletions for git, using git add -A to recover after rm
- Python sys.path shadowing — adding a directory to sys.path exposes ALL its subdirectories as importable packages; adding `software/` shadows the pip-installed `scservo_sdk` with the local copy, breaking LeRobot. Always add the repo root, not a mid-tree directory.
- LeRobot teleop loop design — single FeetechMotorsBus for both arms on one port; prefix motor names (follower_/leader_) to avoid collisions; 1:1 normalized mapping works when arms are physically identical with drive_mode=0
- STS3215 Acceleration register — value 0 means no limit (like Maximum_Velocity_Limit); go_neutral must reset both to 0 on exit or downstream scripts inherit slow ramp rates
- Modular vs. monolithic CAD design — building a part as a union of smaller, independently swappable sub-parts (vs. one single-body design) costs more upfront modeling effort but pays back heavily on iteration speed: a monolithic part requires a full redesign (or full reprint) for a single failed feature, while a modular one lets you reprint/redesign just the sub-part that failed and reuse the rest. Currently being felt directly on the claw redesign (see `docs/debugging/postmortems.md` #5) — still calibrating exactly how much time this saves in practice, not yet a settled rule.
- UVC camera device enumeration on Linux — one physical camera exposes multiple `/dev/videoN` nodes (capture + metadata); only the capture-capable node (check `ID_V4L_CAPABILITIES` via udev, or just try opening it) actually streams frames.
- Lens FOV spec ambiguity — a quoted FOV number is meaningless without knowing which axis (horizontal/vertical/diagonal) and whether it's the full/total angle or a half-angle; manufacturers often publish only one axis. Confirmed Arducam's B0385 "70°(H)" is the full horizontal angle via the manufacturer manual — the "H" already disambiguates the axis, and full-angle is the default convention unless stated otherwise.
- Two UVC cameras of the same make/model can report identical USB serial numbers — cheap OEM UVC bridge chips (this board uses one branded "Vitade AF", VID:PID 0c45:6366) often don't burn a unique serial, so distinguishing two identical cameras by udev/serial alone doesn't work; motion (nudge the camera, watch which video feed moves) is the reliable disambiguator.
- Git loose-object corruption is locally recoverable if the remote has the object — but `git fetch` won't resend a commit your local refs already claim to have, even if the on-disk object is corrupt/missing. The corrupt objects *and* any ref pointing at them have to be removed first, so the negotiation no longer thinks you already have it.
- A servo in position-control mode keeps applying torque toward `Goal_Position` on its own, independent of whatever the host script is doing — a Python polling loop timing out doesn't stop the servo from still pushing. Sustained pressure against an obstruction (not a momentary spike) is what trips overcurrent protection, and it can take most of a generous timeout window to do it.
- FEETECH status/error byte bits are distinct and independently latch-and-report: `OverEle` (bit 3, overcurrent) vs `Overload` (bit 5) are different conditions. The servo's own protection firmware can auto-disable torque on just the affected motor when one trips — independent of what the host's `Torque_Enable` writes say — which is why only one servo can end up detorqued after a stall while the rest of the bus stays enabled.
- Boundary-inclusive vs. exclusive tolerance checks matter operationally, not just in theory: a strict `<` against a threshold a real sensor value can land exactly on (not just get arbitrarily close to) causes a "hang" that's actually just a comparison that can never be satisfied — the joint isn't stuck, the check is unsatisfiable. `<=` (or widening the tolerance) fixes it.
- Terminal-based "hold key to move" (dead-man's switch) control has no true key-up event over a raw SSH terminal — unlike a GUI or direct HID access, there's no way to know a key was *released*, only that bytes stopped arriving. "Held" has to be inferred from the OS's keyboard auto-repeat cadence (treat recent-enough as still-down), which is a real constraint on responsiveness, not just an implementation detail.
- Free-standing multi-DOF arm bases have to resist the *tipping moment* the arm's own weight and motion generate, not just hold static weight — a base sized only for support flexed and let the arm tip over during assembly/testing. Fixed by clamping the base to the table rather than relying on the base's own footprint/mass for stability. See `docs/debugging/postmortems.md` #6.
- PLA screw-in mounting bosses (where a printed link bolts to a servo horn) are a stress concentration distinct from the part's general wall thickness — links that were adequately thick everywhere else still bent specifically at the servo attachment point, requiring local reinforcement there rather than a uniform thickness increase. See `docs/debugging/postmortems.md` #7.
- LeRobotDataset resolution is schema-locked for the life of the dataset — `create()` fixes each camera's recorded shape permanently; there is no in-place "upgrade." A script that assumes one global recording resolution will silently corrupt a `--resume` session on an older dataset created before that assumption existed (see `docs/debugging/postmortems.md` #8) — the safe pattern is to derive recording size from the target dataset's own declared feature shape, not a constant.
- A writer that advances a counter (episode index, in this case) *before* validating the data behind it turns what should be a hard failure into silent corruption — `meta/info.json`'s totals advanced normally while the real parquet/video data behind two of those episodes never existed. Worth checking for this "reserve-then-fill" ordering in any pipeline that separates a count/index update from the data write it's supposed to represent.
- `LeRobotDataset.create()` infers a default `root` from `HF_LEROBOT_HOME`/`repo_id`; `resume()` does not — it raises unless `root` is passed explicitly. Asymmetric defaults between two functions that otherwise feel like a matched pair are an easy thing to miss until the less-common path is actually exercised.
- LeRobot's own guidance: `image_writer_threads` should be sized *per camera* (4 threads/camera), not as one shared pool across all cameras — too few threads doesn't error, it just lets the write queue (unbounded `queue.Queue`) grow silently, so "recording feels laggy/hangs after pressing Enter" can be a threading-starvation symptom with zero exceptions to point at it.
- UVC cameras snap an unsupported requested capture resolution to the nearest supported discrete preset silently (requesting 640×400 on the Arducam OV9782 here returns 640×480 instead — same width, wrong aspect ratio) rather than erroring — always confirm the actual negotiated resolution against a live capture, don't trust the requested value, and downscale in software post-capture if the sensor doesn't natively support the target size.
- Video encode time on this Jetson's ARM cores is dominated by output resolution, not codec choice or GOP/keyframe interval — confirmed by direct benchmark (H.264 was not faster than AV1; GOP size only changed file size, not speed; halving resolution gave a measured ~3.4× speedup). A plausible-sounding hypothesis (codec choice) can still be wrong; benchmark on the actual target hardware before committing to a fix.
- Stream-copy video concatenation (ffmpeg's concat demuxer, used to merge each episode's own encoded video into one per-camera chunk file) can leave a small number of inert padding frames in the container that don't correspond to any real timestamped sample — visible via a raw frame-count decode, invisible to anything (like LeRobot) that addresses frames by timestamp rather than raw position.
- Sizing imitation-learning training by a flat step count (LeRobot's `train.steps` default of 100,000) doesn't account for dataset size — LeRobot's own hardware guide instead recommends sizing by epochs over the dataset (typically 5–10), which for a small ~50-episode dataset works out to a fraction of the flat default (~17.7k–35.4k steps here, not 100k).

---

### Waveshare Bus Servo Adapter (A) — Critical Wiring Note

**UART-Servo mode wiring is straight-through, NOT crossed:**
- Pi TX → Board TX
- Pi RX → Board RX
- GND → GND

This is the opposite of standard UART convention. The board labels its UART pins from the host's perspective. See `docs/debugging/servo-comms-debug-log.md`.

---

## Encoder Wrap-Around — RESOLVED ✅

**Discovered 2026-05-31. Root cause understood 2026-06-01; `calibrate_lerobot.py` rewritten around the fixed flow 2026-06-01/02 (commits `e63aaaa`…`493fbb7`).** Some joints have their physical travel range crossing the STS3215 encoder's 0↔4095 boundary. The absolute magnetic encoder is 12-bit (0–4095 per revolution). If the servo is mounted such that the physical joint stops straddle this boundary, raw encoder readings jump from 4095→0 mid-motion.

### The key insight (2026-06-01)

The STS3215 reports `Present_Position = (raw_encoder − Homing_Offset) mod 4096`, always in 0–4095 (requires Phase bit 4 cleared, done by `configure_motors()`). The consequence: the encoder *seam* (where present jumps 4095↔0) is NOT fixed to the magnet's zero — it sits at the shaft angle where `raw = Homing_Offset`. **Choosing the homing offset moves the seam.**

So the problem isn't "tolerate a wrap" — it's "park the seam in the joint's dead gap (the untraveled arc) so the travel never crosses it." And LeRobot's home-at-center procedure does this automatically: homing at the arc center throws the seam exactly 2048 counts away, which is the center of the opposite (dead) gap. As long as travel < 360°, the gap is non-zero and the seam lands safely inside it.

Worked example — shoulder_lift (ID 8), stops raw 1855 and 202:
- Travel arc = (202 − 1855) mod 4096 = 2443 counts ≈ 215°. Dead gap = 1653 counts ≈ 145°.
- Mid-arc raw ≈ 3076 → `Homing_Offset = 3076 − 2047 = 1029`. Seam at raw=1029, which is the center of the dead gap (202–1855). ✓
- Reported present after homing: stop A (1855) → 826, center (3076) → 2047, stop B (202) → 3269. **Both limits positive, contiguous, ~215° span. No negative EPROM write.**

The `−827` from the original failure only appeared because the OLD script computed `raw + offset` in plain Python **without the mod 4096** that the servo actually applies. The negative write was a symptom, not the disease.

### The correct calibration flow (per joint) — IMPLEMENTED in `calibrate_lerobot.py`

1. `bus.configure_motors()` once up front — clears the Phase bit so present-position reporting is single-turn mod-4096. **The old script never called this** — that was a real latent bug.
2. Hand-move the joint to the **middle** of its travel.
3. `bus.set_half_turn_homings([name])` — resets cal, reads present, writes `Homing_Offset`; the *servo* applies it.
4. `bus.record_ranges_of_motion([name])` — now records present in the continuous homed frame → clean positive range, seam parked in the dead gap.
5. `bus.write_calibration(...)`.

Keep the per-joint loop (prevents unsupported joints swinging under gravity). Just split each joint into "move to middle → Enter" then "sweep both stops → Enter."

`software/calibration/calibrate_lerobot.py` implements this flow exactly (steps 1–5, per-joint loop included) as of commit `493fbb7` (2026-06-02). It is the live, current calibration script — not a stub, not deprecated.

### Answers to the three handoff questions

1. **How does SO-100 handle wrap joints?** It doesn't special-case them — it *avoids* the seam via single-turn mod-4096 reporting (Phase bit) + home-at-center (seam → dead gap). No negative range_min in normal use.
2. **Does `drive_mode=1` fix it?** No. `drive_mode` is only a software sign-flip applied *after* normalization (`100 - norm if drive_mode`) so leader/follower agree on direction. It never touches the encoder, offset, or seam. It cannot reroute the joint onto the short path — the joint physically occupies the 215° arc.
3. **Negative `range_min` in software only?** Not needed if you home correctly (you get 826–3269). But it IS valid in principle: `_normalize`/`_unnormalize` only read range_min/range_max and never require ≥0. Only `_serialize_data` rejects negatives, and only when writing the *unsigned* Min/Max_Position_Limit EPROM registers. (Homing_Offset itself is fine negative — sign-magnitude, bit 11.) So a true-negative range = keep range in JSON, skip the EPROM limit write.

### Affected joints (leader arm, 2026-05-31)

| Joint | ID | Stop A (raw) | Stop B (raw) | Wraps? | Notes |
|---|---|---|---|---|---|
| shoulder_pan | 7 | 944 | 3337 | No ✅ | Clean range |
| shoulder_lift | 8 | 1855 | 202 | **Yes ⚠️** | Goes UP: 1855→4095→0→202; span ~214° |
| elbow_flex | 9 | 831 | 3149 | No ✅ | Clean range |
| wrist_flex | 10 | 2448 | 3970 | Unknown | Suspect yes — showed 0–4095 in calibration run |

Diagnostic command used to confirm:
```bash
python -c "
from lerobot.motors.feetech import FeetechMotorsBus
from lerobot.motors.motors_bus import Motor, MotorNormMode
import time
bus = FeetechMotorsBus(port='/dev/ttyACM0', motors={
    'shoulder_lift': Motor(id=8, model='sts3215', norm_mode=MotorNormMode.RANGE_0_100),
})
bus.connect(); bus.disable_torque()
while True:
    v = bus.read('Present_Position', 'shoulder_lift', normalize=False)
    print(f'\r  {int(v):4d}', end='', flush=True)
    time.sleep(0.05)
"
```

> **The detailed failure analysis of the *old* approach** — why `record_ranges_of_motion` (naive `min()`/`max()`) and `set_half_turn_homings` produced the `-827` negative-EPROM-write `ValueError` — is preserved in [`docs/handoffs/lerobot-calibration-wrap-around.md`](handoffs/lerobot-calibration-wrap-around.md). The corrected understanding (the seam moves with the homing offset; home-at-center parks it in the dead gap) is in "The key insight" above; that's what supersedes it.

### Current state of calibration files

`calibration_follower.json` and `calibration_leader.json` were regenerated with the fixed flow in a clean re-calibration pass on 2026-07-27 — both arms tracking correctly, precise normalization confirmed.

### Remaining implementation work

None — both the physics and the code are done. `calibrate_lerobot.py` was rewritten around the library primitives (see above) on 2026-06-01/02, and the clean re-calibration pass with the fixed script (previously outstanding) was completed 2026-07-27.

---

### move_one.py — current state (2026-05-28)

- Located at `software/low-lvl-setup/move_one.py`
- Uses raw `scservo_sdk` directly (no `_serial_utils` wrapper)
- Interactive ID collection via readchar; SPACE to finish (ESC dropped — SSH eats it)
- On startup: pings each servo, reads current position, enables torque, moves to home position from `config/home.json`
- Home speed: 500 steps/s, accel: 50 (~100 steps/s² units) — conservative startup values
- Home positions stored in `software/config/home.json` (IDs 1–6, leader arm, captured 2026-05-28)

### torque_off.py / flash_angle_limits.py (2026-05-28)
- `torque_off.py`: interactive torque disable, same ID collection as move_one.py
- `flash_angle_limits.py`: reads limits.json, writes MIN/MAX angle limits to servo EPROM for all IDs; servo needs power cycle after

### teleop.py — confirmed working (2026-06-03)

- Located at `software/control/teleop.py`
- Single `FeetechMotorsBus` on `/dev/ttyACM0` with all 12 motors (prefixed `follower_*` and `leader_*`)
- Startup (updated 2026-08-01): safe-enables both arms → `run_startup_sequence` (neutral → recorded startup sequence on both arms → neutral) → disables leader torque → loop starts
- Loop: `sync_read` leader normalized positions (0–100) → 1:1 dict remap → `sync_write` to follower at 50 Hz
- Arms are physically identical (not mirrored), so `drive_mode=0` + 1:1 normalized mapping = matching poses
- No pre-running `go_neutral` needed — teleop handles its own startup sequence
- Usage: `conda activate lerobot && python software/control/teleop.py [--hz 50]`

**Import path gotcha (hit 2026-06-03):** Adding `software/` to `sys.path` to import `go_neutral` shadows the pip-installed `scservo_sdk` with the local copy in `software/scservo_sdk/`. LeRobot's `feetech.py` uses `scservo_sdk.PacketHandler` which doesn't exist in the local SDK → `AttributeError`. Fix: add the repo root (`hexarm/`) to `sys.path` instead, then import as `from software.calibration.go_neutral import go_neutral`.

### go_neutral.py — bug fix (2026-06-03)

`go_neutral` was resetting `Maximum_Velocity_Limit` to 0 after completing but **not** resetting `Acceleration`. Leaving `Acceleration = 20` on the servos caused sluggish ramp-up in the teleop loop. Fixed: both registers are now reset to 0 on completion.

### Neutral pose unification — fixes follower-snap-on-leader-release (2026-08-01)

**Bug:** at teleop startup, the follower would suddenly snap to the leader's position the instant leader torque was dropped (step 2 of the old startup sequence). Root cause: `neutral_follower.json` and `neutral_leader.json` were captured as two separate hand-poses via `record_neutral.py --arm <arm>`. Two independently hand-posed captures are never bit-identical — so each arm parked at a *slightly different* physical position during `go_neutral`, and the loop's first `sync_read` of the leader's actual position yanked the follower to match it.

**Fix:** `record_neutral.py` now always hand-poses the follower only (no `--arm` flag) and writes a single `software/config/neutral.json`. `go_neutral.py` now always drives *both* arms (no `--arm` flag) to that one shared file — identical normalized values sent to `follower_*` and `leader_*` in the same `sync_write`. Since both arms are physically identical with `drive_mode=0` (the same invariant `teleop.py`'s 1:1 leader→follower mapping already relies on), matching normalized values now means matching physical poses, so there's nothing left to snap to. `teleop.py` was updated to load the one `neutral.json` instead of the two per-arm files. The old `neutral_follower.json`/`neutral_leader.json` are left on disk but are no longer read by anything — `neutral.json` must be recaptured via `record_neutral.py` before `go_neutral.py`/`teleop.py` will run.

### Startup sequence feature (2026-08-01)

New capability, motivated by wanting a repeatable choreographed motion (e.g. a wave/wake-up gesture) at the start of every teleop session, on top of the neutral-pose fix above:

- `set_startup_sequence.py` — Enter to arm → 5s countdown (printed each second) → `>>> RECORDING NOW <<<` → records 5s of the leader's hand-performed motion at 50 Hz (torque disabled, leader only) → saves `{"hz": 50, "samples": [...]}` to `software/config/startup_sequence.json`.
- `run_startup_sequence.py` — importable `run_startup_sequence(bus, neutral, sequence)`: velocity/acceleration-limited move to neutral via `go_neutral()` → open-loop `sync_write` playback of the recorded samples onto **both** arms simultaneously (same values to `follower_*`/`leader_*`, same shared-pose invariant as above) → velocity/acceleration-limited move back to neutral via `go_neutral()` again (the "careful" return, handles arbitrary wherever-playback-left-off starting position since `go_neutral` targets an absolute pose). Also runnable standalone.
- `teleop.py`'s startup sequence is now: torque-enable both arms → `run_startup_sequence` (neutral → recorded sequence → neutral) → drop leader torque → teleop loop. New hard prerequisite: `software/config/startup_sequence.json` must exist, or `teleop.py` raises `FileNotFoundError` at startup — **run `set_startup_sequence.py` at least once before the next teleop session.**

### Jetson JP7.2 reflash — CUDA torch on Python 3.12, servo bus reconfirmed (2026-08-04)

**Why:** LeRobot requires Python ≥3.12. JetPack 6.2 (L4T r36.4.7, Ubuntu 22.04) ships Python 3.10, and no cp312 CUDA torch wheel exists for that JetPack version — only cp310. cp312 CUDA torch only exists for JetPack 7.2 (L4T r39.2, Ubuntu 24.04, CUDA 13.2). Rather than a multi-hour from-source torch build on 6.2, reflashed to 7.2 to use prebuilt cp312 wheels.

**Method:** Jetson ISO (USB installer, no x86 host PC needed). A QSPI capsule firmware update was applied first (firmware now r39-generation). Target storage was the microSD card; the NVMe (`/data`) was deliberately left untouched and mounts intact post-reflash (`nofail` in `fstab` — see Setup Status). First install attempt failed at subiquity late-commands with exit 127; root cause was no network during install (the installer image lacks `dhclient` and the interface was `state DOWN`). Second attempt, with network configured on the installer's network screen, succeeded. Note for next time: Ethernet is `enP8p1s0` (PCIe NIC), not `eth0`.

**Python environment:** `/data/lerobot-env`, a venv on system Python 3.12 — deliberately not conda, since the Jetson CUDA wheels link against system CUDA/glibc/libstdc++ and conda's bundled copies of those cause `GLIBCXX`/CUDA resolution failures on Jetson. Installed: torch 2.12.0, torchvision 0.27.0+78839c2, onnxruntime-gpu 1.28.0 (all cp312/CUDA 13.2/cuDNN 9, from the [Shattered217/Jetson-Orin-Wheels](https://github.com/Shattered217/Jetson-Orin-Wheels) `7.2.0` release), numpy 2.2.6 (downgraded by LeRobot's `<2.3.0` pin), lerobot 0.6.1 (editable install from `/data/lerobot`). `torch.cuda.is_available()` verified `True`.

LeRobot 0.6.1's `pyproject.toml` pins `torch>=2.7,<2.12.0`, which excludes the only available Jetson wheel (exactly 2.12.0) by one release — without patching, `pip install -e .` silently falls back to a generic manylinux CPU-only torch 2.11.0. Patched the bound to `<2.13.0`/`<0.28.0` (torchvision) and committed the patch, along with two pre-existing Python-3.10-compat edits from the abandoned JP6.2 attempt (harmless under 3.12, kept as-is), to a local-only branch `jetson-jp7.2-local` in `/data/lerobot` — `main` stays clean for future `git pull`, this branch is what's actually checked out and what the editable install uses.

**Servo bus — re-verified, no driver work needed:** the reflash handoff initially flagged the CH343 USB-serial bridge as a blocker (`ch341` module not found, `/sys/bus/usb-serial/` absent). Checking `journalctl -k` (readable without sudo via the `adm` group) showed the actual boot-time enumeration: `cdc_acm 1-1:1.0: ttyACM0: USB ACM device` — the CH343 chip on the Waveshare board presents as a CDC ACM device on Linux, not a vendor-specific CH34x device, so the in-kernel `cdc_acm` driver handles it with zero extra work. This matches what a prior session had already documented (see Compute — Jetson Orin Nano Super, above) but wasn't cross-referenced during the reflash. Confirmed end-to-end: `FeetechMotorsBus(port='/dev/ttyACM0', motors={}).broadcast_ping()` returned all 12 servo IDs (1–12, model 777/STS3215) after `bus.connect(handshake=False)`.

**Known follow-ups, not yet done:** Super Mode may be unavailable — NVIDIA documents a JP7.2.0 bug where installing via Jetson ISO doesn't configure the Orin Nano dev kit for Super Mode (currently on 25W, MAXN SUPER missing); expected fixed in 7.2.1. 252+ pending apt updates deliberately not applied (blanket `apt upgrade` on Tegra risks the vendor kernel).

**`torchcodec` import failure — root-caused and fixed (2026-08-05).** `pip install -e ".[feetech,dataset]"` (run to unblock `record_dataset.py`, which needs the `datasets` package) pulled in `torchcodec==0.11.1` per the aarch64 pin in `pyproject.toml`. Importing it raised `RuntimeError: Could not load libtorchcodec` — the error message's own hint ("PyTorch version not compatible with this version of TorchCodec") looked like it might confirm the torch-2.12-vs-torchcodec-0.11 mismatch flagged in the JP7.2 reflash writeup above, but `ldd` on `libtorchcodec_core6.so` (the build matching the system's installed FFmpeg 6.1.1 libs) showed it was actually a plain missing-shared-library problem, unrelated to torch: `libavdevice.so.60` and `libavfilter.so.9` weren't installed, even though sibling packages `libavutil58`/`libavformat60`/`libavcodec60`/`libswscale7`/`libswresample4` (same `7:6.1.1-3ubuntu5` build) already were. **Fix applied:** `sudo apt install libavdevice60 libavfilter9` (pulled in `libpostproc57` as a dependency, same `7:6.1.1-3ubuntu5` version as everything else already on the box — 0 upgraded, no kernel/driver risk). Verified: `from torchcodec.decoders import VideoDecoder` now imports cleanly, `torch.cuda.is_available()` still `True` at torch 2.12.0. No torch/torchcodec version mismatch ever existed — the pyproject.toml comment about "0.12 needs torch==2.12" was a red herring for this particular failure. This was a real, immediate blocker (not a defer-to-later item) because `get_safe_default_video_backend()` (`lerobot/utils/import_utils.py`) picks `torchcodec` via `importlib.util.find_spec()`, which only checks that the package is *installed*, not that it *imports successfully* — so it would have hard-crashed the first video-decode call (training, `lerobot-dataset-viz`, etc.) had it shipped unfixed.

### Dataset recording — 50 episodes, resolution/speed fix, phantom-episode incident (2026-08-10)

**Goal for the session:** record the pick-and-place demonstration dataset (target: 50 episodes) now that arms, cameras, and startup sequence were all confirmed ready as of session 11.

**Hardening before recording, driven by real failures hit early in the session:**
- Arms weren't returning to neutral after the *last* episode of a session (only between episodes) — fixed.
- A stale, empty dataset directory from an earlier crashed attempt caused `FileExistsError` on `create()` — the fix was just deleting the stale directory; not a code bug.
- Pressing ENTER to finish an episode appeared to hang for ~15s before Ctrl-C would even register. Root cause: `image_writer_threads=4` was being shared across 2 cameras instead of LeRobot's own documented recommendation of 4 threads *per camera* — the unbounded write queue was silently backlogged with zero console feedback. Fixed: `image_writer_threads = 4 * len(cameras)`.
- `bus.write()`/`bus.read()` default to `num_retry=0` — a single dropped status packet during `safe_enable_torque()` raised `ConnectionError` and crashed a whole session. Fixed with `num_retry=3` across all scripts using this pattern (see FeetechMotorsBus API section above).
- `--resume` raised `ValueError: resume() requires an explicit 'root' directory` — unlike `create()`, `resume()` has no default root inference. Fixed by passing `root=HF_LEROBOT_HOME / repo_id` explicitly.
- Added a full-width, high-contrast on-screen banner when recording starts — the monitor is several meters from the robot station, plain terminal text wasn't visible from there.

**Video encode speed investigation:** the ~2-minute wait after each episode (image-queue flush + video encode) was benchmarked directly on hardware rather than guessed at. Findings, in order of what turned out to matter: GOP/keyframe interval doesn't affect encode speed (only file size); switching codec (AV1 → H.264, even `ultrafast`) is *not* faster on this Jetson's ARM cores — the original hypothesis, disproven by direct measurement; **resolution is the dominant lever** — 1280×800 → 640×400 gave a measured ~3.4× speedup (71.5ms/frame → 21.2ms/frame). The camera doesn't support requesting 640×400 capture directly (it silently snaps to 640×480, the wrong aspect ratio) — confirmed via direct hardware test before committing to an approach — so the fix captures at native 1280×800 and downscales in software (`cv2.resize`, `INTER_AREA`) before writing.

**Phantom-episode data-loss incident — see `docs/debugging/postmortems.md` #8 for the full root-cause writeup.** Short version: the resolution fix above applied unconditionally, but `hexarm/pick_and_place` (created earlier, before the fix existed) was already schema-locked at 1280×800; resuming it with 640×400 frames silently produced 2 uncommitted "phantom" episodes — `info.json`'s counters advanced with no real data behind them, and the underlying frames were unrecoverable by the time it was caught. Root-caused via file-mtime forensics, fixed by deriving recording resolution dynamically from the target dataset's own feature schema (`dataset.features[...]["shape"]`) instead of a fixed constant, and `info.json` was hand-repaired back to the true state (3 valid episodes). Decision going forward: a dataset's resolution is fixed for its lifetime — to get the faster resolution, record into a **new** `repo_id` (`hexarm/pick_and_place_v2`) rather than resizing an existing one in place. The original `hexarm/pick_and_place` (3 valid episodes, 1280×800) was kept on disk, untouched, rather than deleted — cheap to keep, no reason to lose real data for a naming preference.

**Recording, verification, and result:** all 50 episodes recorded into `hexarm/pick_and_place_v2` (640×400 @ 30fps, ~28.3k total frames) across several sessions today. Verified structurally sound — `info.json` totals match the real data table exactly, every episode's first/last frame decodes correctly through the actual `LeRobotDataset` load path (not just file-existence checks), no orphaned/incomplete episode directories left on disk. One rabbit hole worth noting for next time: the raw video *container* reported ~136 more frames (via both `cv2`'s metadata and a real PyAV decode) than the data table's frame count — traced to inert padding from ffmpeg's stream-copy episode concatenation (each episode's own `from_timestamp`/`to_timestamp` × fps matches its real frame count exactly), not data loss; LeRobot addresses frames by timestamp, so the padding is never read during training. Built a visual QA artifact — start/mid/end thumbnail frames from both cameras for all 50 episodes — for the one thing no automated check can confirm: whether the leader arm ever creeps into the overhead camera's frame (an explicit LeRobot dataset-quality rule, see the Camera Placement Research entry in the Vision section above). Decision after reviewing: not worth blocking on, given how few frames would be affected — to be fixed later if it actually shows up as a training problem, not preemptively.

**Training-time research (Jetson vs. cloud):** benchmarked real ACT policy training step time on this Jetson — built the actual policy LeRobot would train (same architecture, same input shapes as the real dataset, same batch size 8, FP32 — LeRobot's default has no mixed precision) and timed 20 real steps: **1.29s/step measured**. Cross-referenced against LeRobot's own hardware guide, which sizes training by epochs over the dataset (5–10 epochs), not a flat step count — for this dataset that's ~17.7k–35.4k steps, projecting to **~6.4–12.7 hours locally**. The same guide's own published anchor for a near-identical setup (RTX 4090, ACT, batch 8, ~50-episode dataset) is **~30–90 minutes**, and a rented RTX 4090 costs well under $1 for a full run. Decision: train in the cloud (`lerobot-train ... --job.target=a10g-large` via HF Jobs, or a rented RTX 4090) rather than tying up the Jetson — which is also the robot's control computer — for half a day per run, especially with multiple training iterations likely.

### Jetson training crash — RAM exhaustion diagnosed and fixed with zram (2026-08-13)

**Local training crashed the Jetson twice — see `docs/debugging/postmortems.md` #9 for the full root-cause writeup.** Short version: two hard freezes (no panic, no OOM-kill, physical power cycle required both times) while running `lerobot-train`'s local 300-step ACT benchmark. The first crash's last kernel log line (`nvme0: I/O tag ... timeout`) initially pointed at NVMe power delivery, but a second, instrumented repro — `tegrastats` and the training command's stdout both logged to the eMMC root instead of `/data`, specifically so telemetry would survive a repeat crash — caught the real mechanism: RAM hitting 97–98% of the board's 7.3GB unified pool with 0B swap configured, during the dataloader's prefetch warmup. `systemd-oomd` never armed to catch it (silently disabled — this kernel doesn't expose `/proc/pressure/memory`, which the service requires). Fixed with `zram-tools` (compressed-RAM swap, chosen over a disk-backed swapfile to avoid adding I/O load to the drive already suspected of instability): had to override the package's default `ALGO=lz4` to `zstd` (this Tegra kernel's zram driver doesn't support lz4 — only lzo/lzo-rle/zstd) and its default `SIZE=256` (MiB, far too small) to `PERCENT=50` (~3.7GB). Verified by re-running the identical benchmark with telemetry watching again — swap absorbed ~1.4GB at the same peak that killed the box twice before, and this time training ran clean through all 300 steps (loss 28.07 → 3.00) with a fully-saved checkpoint.

**Re-benchmarked training throughput with the fix in place:** the full 300-step run averaged ~0.87s/step at steady state (`updt_s` in the training log) after a ~40s warmup — noticeably faster than the earlier 1.29s/step estimate above (that number came from a synthetic 20-step benchmark script, not a real end-to-end `lerobot-train` run against the actual dataset/dataloader). At this pace, a full 5–10 epoch run (~17.7k–35.4k steps) projects to roughly **4.3–8.6 hours locally** — still well over the ~30–90 minutes a rented RTX 4090/HF Jobs run would take, but the crash risk that originally motivated moving to the cloud is now resolved. **Decision, updated:** run the first full training attempt locally on the Jetson rather than setting up a cloud job — it's free, the crash is fixed, and validating the full local pipeline end-to-end once is worth the wait for a first attempt. Cloud remains the better choice for faster iteration if multiple training runs are needed afterward.

### Full training run completed, checkpoints evaluated, run_policy.py written (2026-08-14)

**Training ran clean, no crash.** Launched `lerobot-train --steps=25000` (`--job_name=act_pick_and_place_v2`, `--save_freq=5000`) inside `tmux` specifically so a dropped SSH connection couldn't kill it — a different failure mode from the RAM-exhaustion freeze postmortem #9 covers, since here the Jetson itself stays healthy but a bare foreground process would still die if its parent SSH session hung up. Also left `tegrastats` logging in the background at a coarser 5s interval (vs. the 200ms used for the crash repro) to keep the file size sane over a multi-hour run. Training finished all 25,000 steps in ~6h12m (18:24:21 → 00:36), confirmed via three independent signals: `uptime` showed continuous boot time predating the run start (no reboot), the `tmux` session was never recreated, and all 5 checkpoints (`005000`/`010000`/`015000`/`020000`/`025000`, plus a `last` symlink) landed on disk with evenly-spaced timestamps matching the measured per-step pace.

**No loss-curve history survived to review after the fact** — `wandb.enable=false` was set (fully offline/local run), `lerobot-train` doesn't write its own metrics log file to disk, and `tmux`'s scrollback buffer had long since rolled past the ~250 progress lines a 6-hour run produces by the time anyone thought to check. The only usable signal left was checkpoint weights themselves. Wrote a standalone eval script (`/tmp/.../eval_checkpoints.py`, not committed — one-off) that loads each of the 5 checkpoints via `policy_cls.from_pretrained()` + `make_pre_post_processors()` and runs 50 forward-pass-only batches (`policy.forward()`, no gradient) against the training set, using `resolve_delta_timestamps()` to reconstruct the same action-chunked batch shape `lerobot-train` uses internally (a plain `DataLoader` without this produces the wrong action-tensor shape and crashes `F.l1_loss`). Result: L1 loss dropped monotonically across every checkpoint — 0.1742 (5k) → 0.1354 (10k) → 0.1124 (15k) → 0.1067 (20k) → **0.0942 (25k)** — with the final checkpoint confirmed as the best of the five, no late-run overfitting. One architectural note worth remembering: `kld_loss` comes back empty in eval mode — ACT's CVAE encoder only runs during training (it needs the real future actions to encode a "style" latent from, which isn't available at inference time), so only `l1_loss`/`loss` are meaningful post-training metrics.

**Wrote `software/control/run_policy.py` for running the policy on the physical arm — not yet run.** No existing script covered this: LeRobot's own `lerobot-record`/`lerobot-rollout`/`lerobot-eval` all require `--robot.type` to be one of a fixed list of built-in robot classes, and hexarm (like all the other custom control scripts here) isn't one of them. The new script mirrors `record_dataset.py`'s hardware wiring (`FeetechMotorsBus`, `OpenCVCamera`) but drives only the follower — no leader arm involved, since the policy replaces the human entirely — and uses LeRobot's own `predict_action()` helper (`lerobot.common.control_utils`) for the actual inference step rather than a hand-rolled version, so the tensor conversion/normalization/postprocessing exactly matches what LeRobot's built-in robot classes do. Safety approach (the more cautious of two considered options): dead-man's-switch gated, identical convention to `go_neutral.py --diagnostic` — the policy's predicted action is only ever written to the servos while SPACE is held, checked fresh every tick, released freezes in place within ~33ms regardless of what was just predicted. Verified everything checkable without hardware: syntax, all LeRobot API imports resolve, the actual final checkpoint loads onto CUDA correctly, and the `action`/`observation.state` feature names (`{joint}.pos` × 6) and camera shapes (400×640×3) the script assumes were confirmed directly against the dataset's real metadata rather than guessed. Hardware I/O itself (bus/camera connect, real servo writes) is the one thing that can only be verified by actually running it.

**Next up:** `source /data/lerobot-env/bin/activate && cd /data/hexarm && python software/control/run_policy.py` — hold SPACE in short bursts first and watch what the policy tries to do before committing to longer holds.

---

### First hardware policy run (v2), grazing/near-clip found, re-recorded and retrained (v3) — logged retroactively (2026-08-21)

**v2 checkpoint was actually run on hardware.** Exact date not logged — it happened between session 14 (2026-08-14, checkpoint confirmed best-of-5 but not yet run) and the v3 dataset recording below (2026-08-20), outside a tracked Claude Code session, so there's no session-log entry for the run itself. `run_policy.py` worked as designed: dead-man's-switch gated, SPACE held in short bursts, task completed successfully. But two close calls surfaced that the offline eval numbers gave no warning of — full root-cause writeup in [`postmortems.md` #10](debugging/postmortems.md#10-first-hardware-policy-run--claw-grazing-the-block-near-clipping-the-bowl-lip): the claw would sometimes graze the block while closing on it during the pick (risking a break — PLA claw, already flagged fragile in postmortems #4/#5), and the drop-off trajectory toward the bowl often passed just over the bowl's top lip with little clearance. Both are the policy faithfully reproducing tight margins that were already present in the `pick_and_place_v2` demonstrations themselves, not a policy-quality problem — L1 loss doesn't measure real-world clearance.

**Fix — re-recorded the dataset, not just retrained on the same data.** New 50-episode dataset, `hexarm/pick_and_place_v3` (recorded 2026-08-20, 35,661 frames vs. v2's ~28.3k — same episode count, longer/more deliberate motions), demonstrating two explicit changes: opening the claw wider by default before closing on the block, and going deliberately higher over the bowl's lip on the drop-off. All ACT hyperparameters kept identical to the v2 run (chunk_size=100, n_action_steps=100, kl_weight=10.0, dropout=0.1, no image augmentation) — the only variable changed on purpose was the demonstration data itself.

**Training — completed, but with a logging gap.** Launched `lerobot-train --steps=30000` (`--job_name=act_pick_and_place_v3`, `--save_freq=5000`) 2026-08-20 16:49, finished 2026-08-21 04:56 (~12h07m — all 6 checkpoints landed on disk with clean, evenly-spaced timestamps through `030000`, `last` symlink updated, no crash). One anomaly worth flagging: `outputs/train/act_pick_and_place_v3.log`'s stdout/stderr capture stopped at ~step 5,700 (18:16, only 27 minutes in) even though training clearly kept running and checkpointing correctly for another ~10.75 hours after that — so there's no in-log record of *why* it stopped, only confirmation via checkpoint timestamps that the process itself was healthy throughout. Separately, the run's per-step pace was noticeably slower than v2's: v2 averaged ~0.89s/step (25k steps / 6h12m); v3 averaged ~1.45s/step (30k steps / 12h07m) despite the visible early progress-bar rate (~1.1 step/s ≈ 0.9s/step) looking normal — cause not diagnosed, since the same logging gap that lost the loss curve also lost any telemetry that could explain the slowdown. Next time: confirm the run is inside `tmux` with logging that's actually verified to keep flushing (v2's session explicitly used `tmux` for SSH-drop protection; unclear whether v3's was set up the same way).

**Checkpoint eval — v3 confirmed better than v2, no overfitting.** Same method as session 14 (one-off script, not committed, loads each checkpoint + runs 50 forward-pass-only batches against the training set, `resolve_delta_timestamps()` to reconstruct the action-chunked batch shape `lerobot-train` uses internally): L1 loss dropped monotonically across all 6 checkpoints — 0.1307 (5k) → 0.1064 (10k) → 0.0961 (15k) → 0.0857 (20k) → 0.0759 (25k) → **0.0738 (30k)** — final checkpoint confirmed best of 6, no late-run overfitting, and a lower final loss than v2's 0.0942 (not a strictly apples-to-apples comparison since it's a different dataset, but a reasonable signal the fit is at least as good). `run_policy.py`'s `DEFAULT_CHECKPOINT` updated to point at `outputs/train/act_pick_and_place_v3/checkpoints/last/pretrained_model`.

**Next up:** run `run_policy.py` against the physical follower arm again, this time watching specifically for whether the wider claw opening and higher drop-off arc actually fixed the two postmortem #10 behaviors — not just "probably better." Close out postmortem #10's TODO once confirmed.

---
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

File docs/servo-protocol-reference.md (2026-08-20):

# STS3215 Servo Protocol Reference

Practical reference for the FEETECH STS3215 half-duplex TTL serial protocol,
as actually exercised by this project. For the complete register map beyond
what's covered here, see the vendor sources in `docs/component_specs/`:
`ST3215 Communication Manual.pdf`, `ST3215-general-manual.pdf`,
`sts3215_memory_table.xlsx`, `Servo-bus-schematic.pdf`.

Most code in this repo talks to servos through LeRobot's `FeetechMotorsBus`
(named fields like `"Present_Position"`, `"Goal_Position"`), not raw
register addresses — this doc is for the raw-protocol layer underneath that
abstraction (`software/scservo_sdk/`, `software/low-lvl-setup/*.py`), and
for understanding what the abstraction is actually doing on the wire.

## Packet framing

```
0xFF 0xFF | ID | LEN | INST | PARAMS... | CHECKSUM
```

- `CHECKSUM = ~(ID + LEN + INST + PARAMS) & 0xFF`
- `LEN` = number of bytes *after* the LEN field itself (`INST` + `PARAMS` +
  `CHECKSUM`)
- Broadcast ID = `0xFE` (254) — servo acts but sends no reply. Used for
  `SYNC_WRITE`.

## Key instructions

| Instruction | Code | Notes |
|---|---|---|
| PING | 0x01 | Servo responds with a status packet — reports model number `777` for STS3215. Cheapest health check available. |
| READ | 0x02 | Read N bytes starting at an address |
| WRITE | 0x03 | Write bytes starting at an address |
| SYNC_WRITE | 0x83 | Broadcast write to multiple servos in one transaction — this is what `bus.sync_write()` uses under the hood, and why a 6-joint goal update costs one bus transaction, not six |

## Key register addresses confirmed in use

| Register | Address | Notes |
|---|---|---|
| ID | 5 | EPROM — requires lock/unlock before writing |
| BAUD_RATE | 6 | EPROM — `0` = 1 Mbps (factory default), `1` = 500K, etc. |
| TORQUE_ENABLE | 40 | SRAM — `1` = enabled |
| GOAL_POSITION_L/H | 42–43 | SRAM — 0–4095 raw range |
| PRESENT_POSITION_L/H | 56–57 | SRAM — read-only |

Everything else this project touches (`Homing_Offset`, `Min/Max_Position_Limit`,
`Maximum_Velocity_Limit`, `Acceleration`) is written through LeRobot's
`FeetechMotorsBus.write()`/`.read()` by field name — see the full memory
table in `sts3215_memory_table.xlsx` for their raw addresses if working below
that abstraction.

## Hardware-verified behavior (the parts no datasheet page will tell you)

- **Wiring is straight-through, not crossed.** The Waveshare Bus Servo
  Adapter labels its pins from the host's perspective: TX→TX, RX→RX. This
  is the opposite of the usual UART cross-wiring convention and was the
  root cause of an initial "no response at all" failure — full chronology
  in `docs/debugging/servo-comms-debug-log.md`.
- **A serial console on the servo UART silently eats bytes.** If comms are
  flaky in a way that looks like framing errors, check
  `systemctl is-enabled serial-getty@<port>` (or `/proc/cmdline` for a
  kernel console) before suspecting the protocol layer. This bit twice —
  once on the Pi, reconfirmed as a risk on the Jetson.
- **`readPort()` should stay stock.** A custom resync layer was added at
  one point to work around what looked like intermittent framing errors; it
  was based on a self-consistent but wrong theory (the real cause was the
  serial-console byte-stealing above) and was reverted. Any retry/error
  recovery belongs in `software/low-lvl-setup/_serial_utils.py`
  (`ping_with_retry`, etc.), not in the packet-parsing layer.
- **`timeout=0.1`, not `timeout=0`, when opening the port.**
  `timeout=0` sets `O_NONBLOCK` on the fd, which makes `ser.read()` return
  immediately regardless of the VMIN termios setting — this silently
  breaks every SDK read. `port_handler.py`'s one deliberate deviation from
  upstream is opening with `timeout=0.1` so `_serial_utils.set_vmin(ser,
  vmin=1)` can actually take effect.
- **`Present_Position` already has the homing offset applied in hardware,
  even with `normalize=False`.** The servo computes
  `Present_Position = (raw_encoder − Homing_Offset) mod 4096` internally
  and reports the wrapped 0–4095 result — there's no way to read the
  "pre-offset" raw encoder value directly. This mod-4096 wrapping requires
  Phase register bit 4 (`0x10`) to be cleared, which LeRobot's
  `configure_motors()` does for `sts3215`. This was the key insight behind
  fixing the encoder wrap-around calibration bug (`docs/context.md`,
  "Encoder Wrap-Around" section) — the earlier assumption that
  `normalize=False` reads were offset-independent was wrong.
- **`num_retry` defaults to 0** on `bus.read()`/`bus.write()` — a single
  dropped status packet raises `ConnectionError` and crashes an unattended
  script. Pass `num_retry=3` (or similar) on any call in a script meant to
  run without a human watching it; LeRobot's own internal cleanup code
  (`disable_torque()`) uses `num_retry=5` for the same reason.
- **A servo in position mode keeps driving toward `Goal_Position` under
  torque** even after a host-side polling loop has given up and timed out.
  Sustained contact with an obstruction (not a momentary spike) is what
  trips the servo's own overcurrent (`OverEle`) protection fault, which
  auto-disables its torque — a stalled/timed-out script on the host side
  does not, by itself, stop the servo from pushing.

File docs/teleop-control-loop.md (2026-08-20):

# Teleop Control-Loop Design

Covers `software/control/teleop.py`'s steady-state loop and the startup
sequence around it. `record_dataset.py` runs the identical tick (see below)
with dataset-recording added on top — this doc is the shared reference for
both.

Related: [ADR 0002 — single-bus servo topology](adr/0002-single-bus-servo-topology.md)
for why one bus carries both arms at all.

## Architecture

One `FeetechMotorsBus` holds all 12 motors, named `follower_<joint>` /
`leader_<joint>` (`build_bus()`). Both arms share calibration-driven
normalization (`MotorNormMode.RANGE_0_100`), so a leader position and its
mirrored follower position are directly comparable numbers — no separate
coordinate transform between the two arms.

## Startup sequence (before the loop starts)
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

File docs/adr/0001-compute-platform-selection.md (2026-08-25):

# ADR 0001 — Compute Platform: Raspberry Pi Zero 2W → Jetson Orin Nano Super

**Status:** Accepted (decided 2026-05-26)

## Context

Hexarm's original compute platform was a Raspberry Pi Zero 2W, driving the servo
bus over its GPIO UART. Two constraints made it a dead end for where the project
was headed:
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

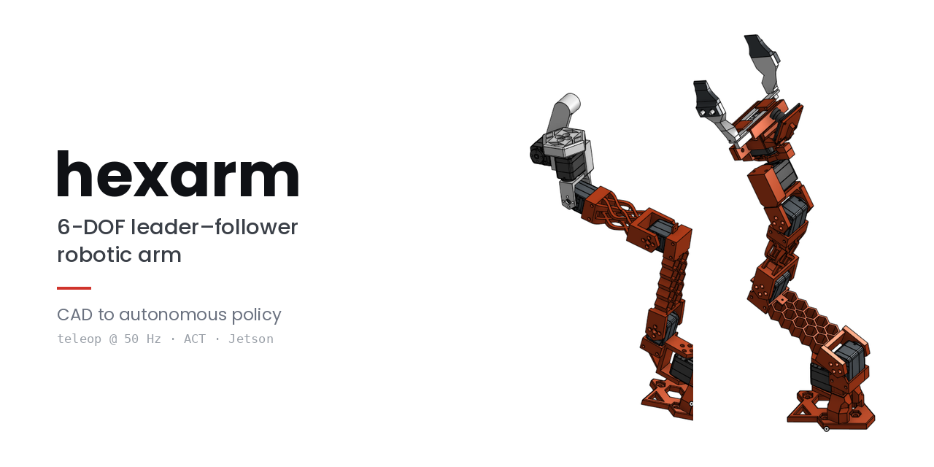
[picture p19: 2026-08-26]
media/social-preview.png

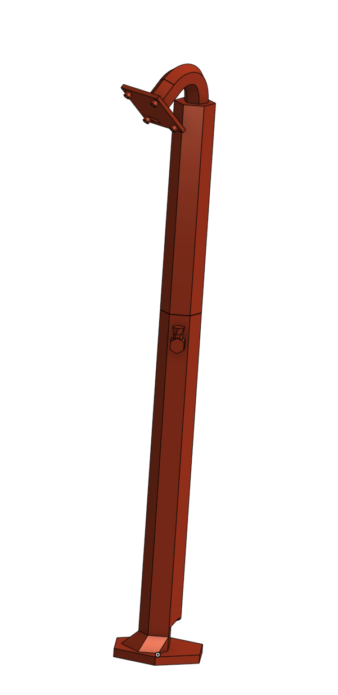
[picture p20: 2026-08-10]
cad/renders/overhead_camera_mount.png

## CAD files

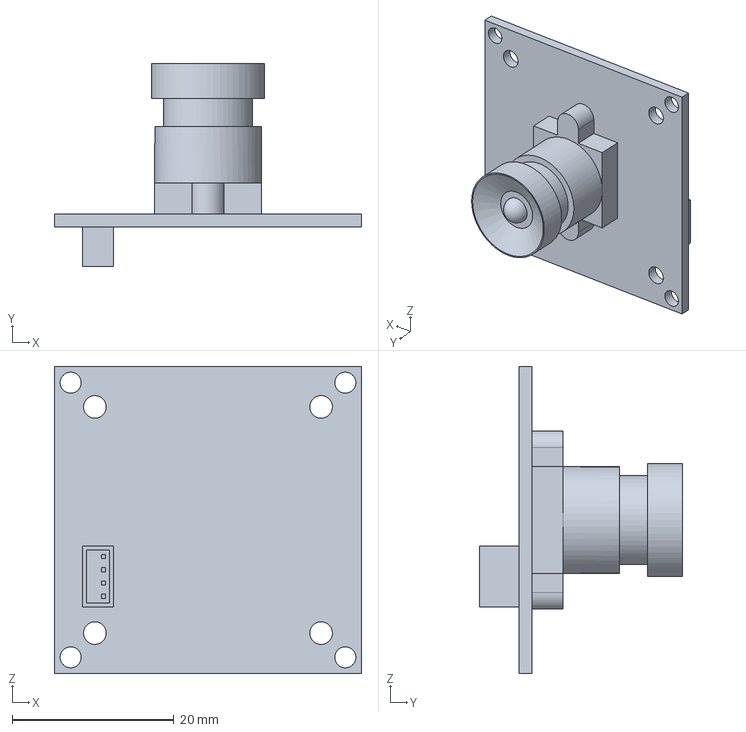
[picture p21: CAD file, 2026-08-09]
cad/exports/arducam_b0385.step
38.0 x 25.1 x 38.0 mm

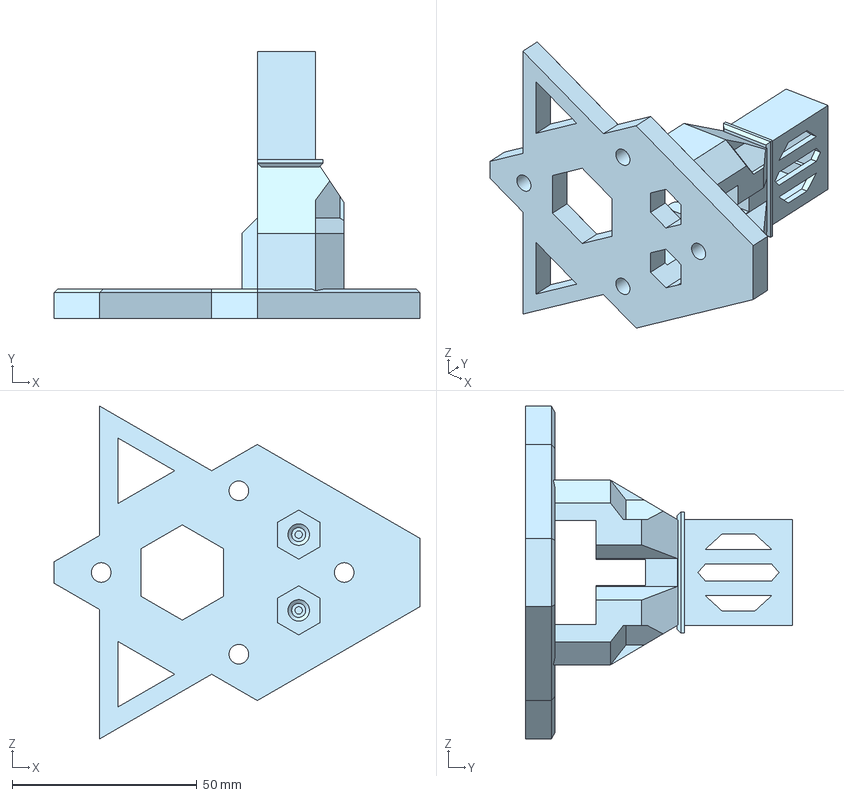
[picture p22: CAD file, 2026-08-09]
cad/exports/follower/base.step
99.0 x 72.2 x 90.0 mm

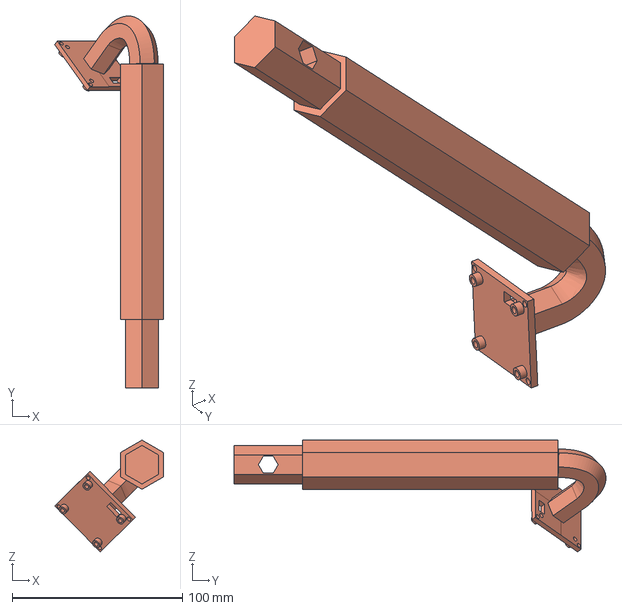
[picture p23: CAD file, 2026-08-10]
cad/exports/overhead camera mount/Overhead Cam Mount - Extension.step
63.7 x 218.3 x 65.6 mm

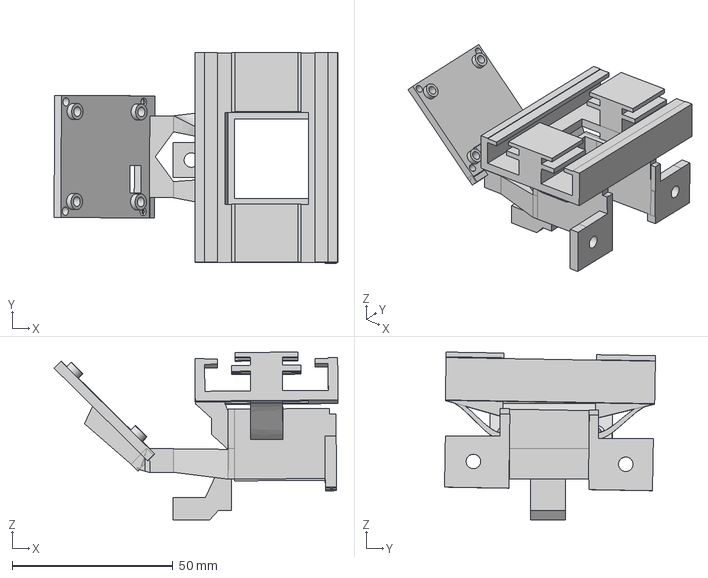
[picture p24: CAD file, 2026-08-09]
cad/exports/follower/claw.step
88.3 x 65.7 x 52.2 mm

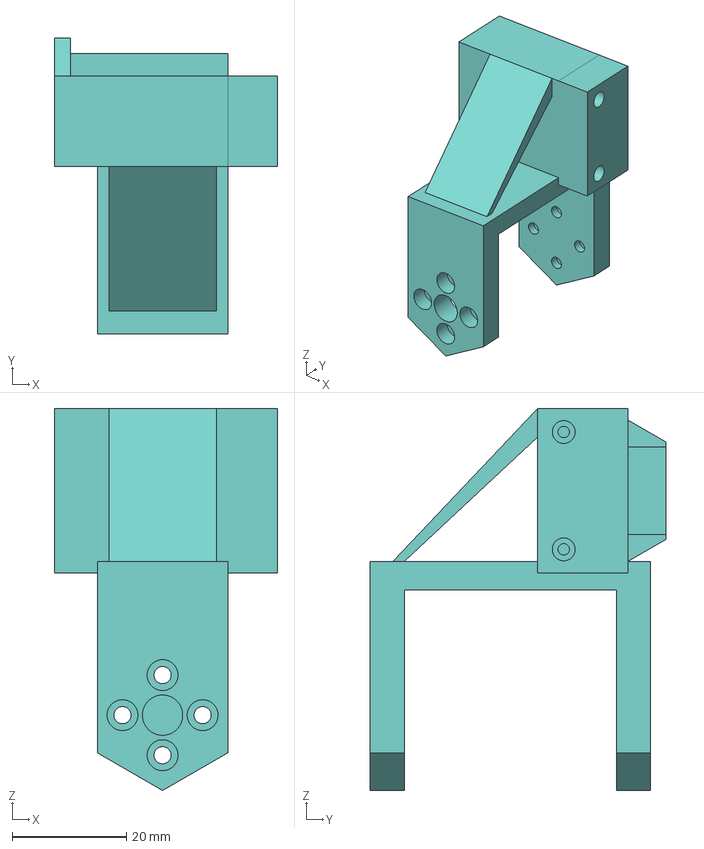
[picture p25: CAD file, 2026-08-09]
cad/exports/leader/link1.step
39.0 x 51.7 x 66.7 mm

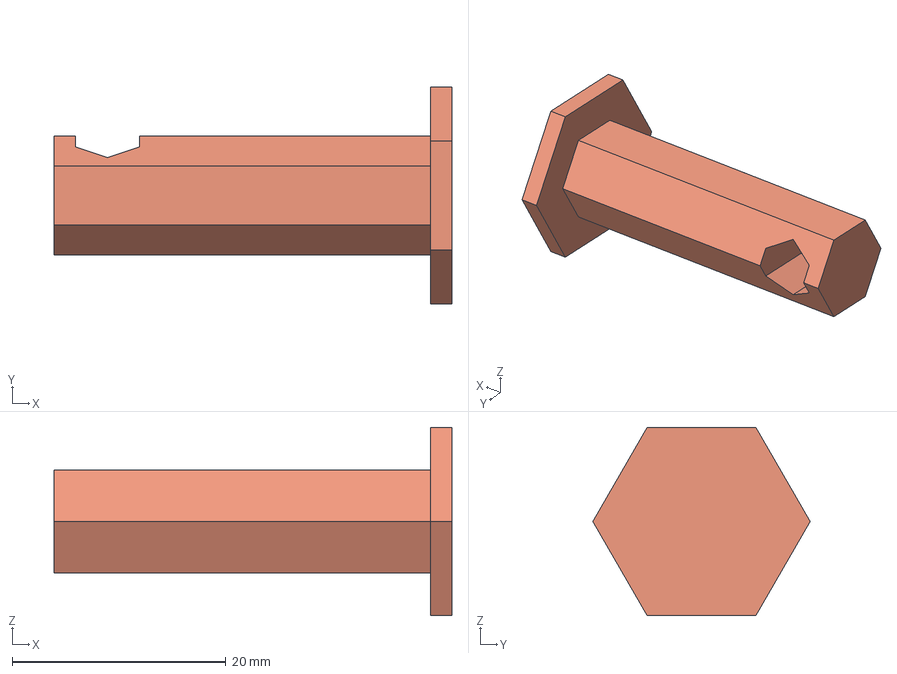
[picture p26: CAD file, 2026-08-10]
cad/exports/overhead camera mount/Overhead Cam Mount - Key.step
37.2 x 20.3 x 17.6 mm

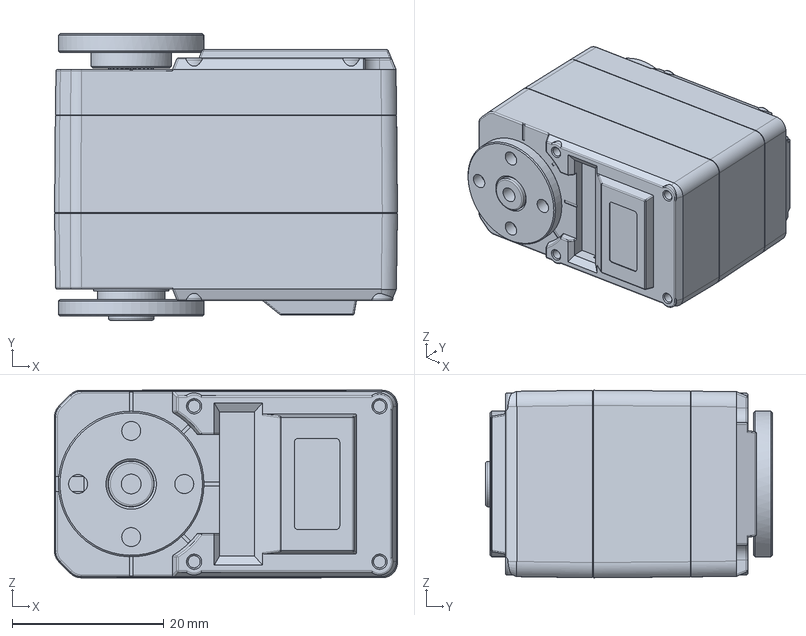
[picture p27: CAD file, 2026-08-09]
cad/exports/sts3215_servo_reference.step
45.2 x 37.8 x 24.7 mm

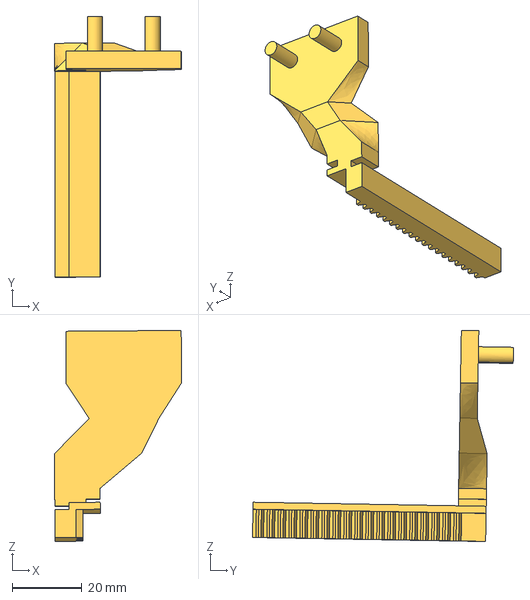
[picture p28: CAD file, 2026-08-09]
cad/exports/follower/top_rack.step
36.4 x 74.7 x 60.4 mm

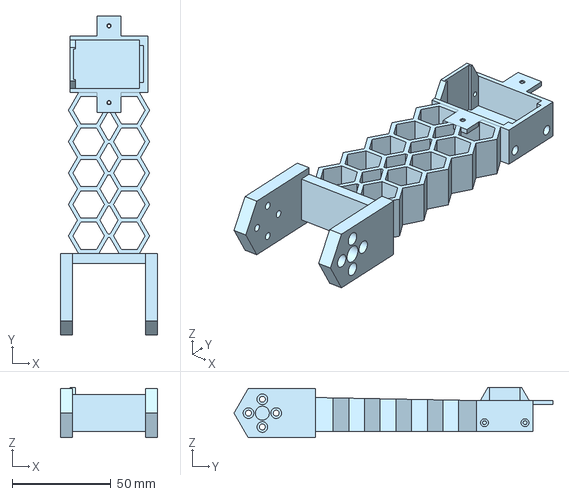
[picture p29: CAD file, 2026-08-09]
cad/exports/leader/link2.step
49.1 x 161.1 x 25.4 mm

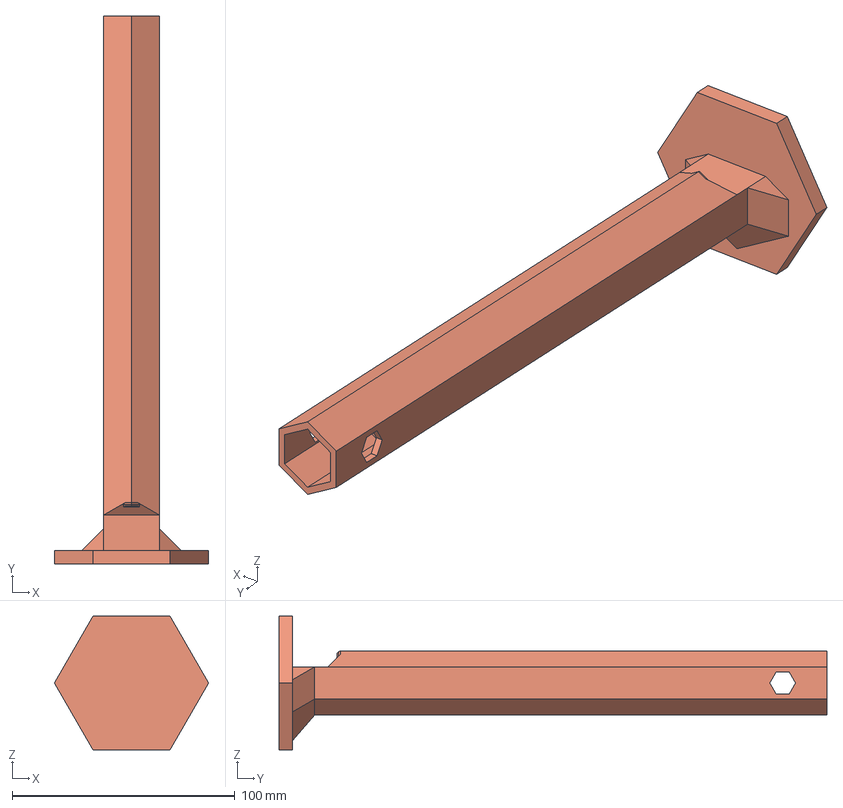
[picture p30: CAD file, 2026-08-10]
cad/exports/overhead camera mount/Overhead Cam Mount - Base.step
69.3 x 246.0 x 60.0 mm

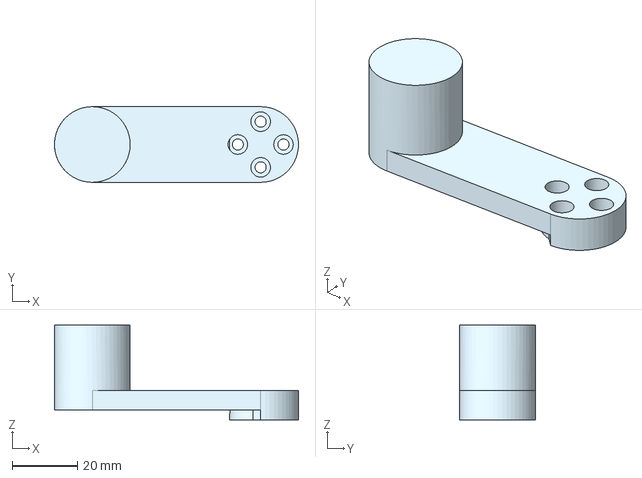
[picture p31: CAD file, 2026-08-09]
cad/exports/leader/crank.step
74.8 x 23.2 x 29.0 mm

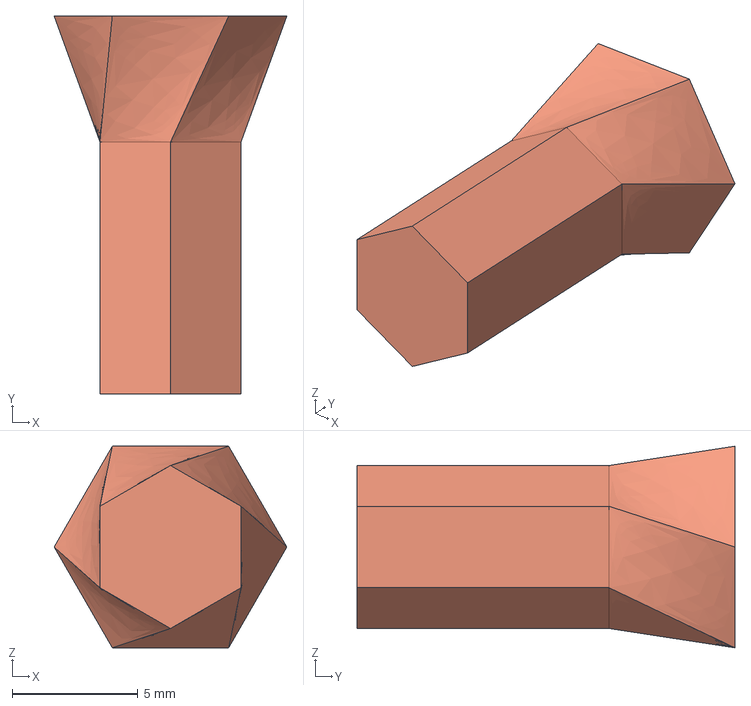
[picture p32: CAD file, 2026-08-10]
cad/exports/overhead camera mount/Overhead Cam Mount - Lock.step
9.24 x 15.0 x 8.00 mm

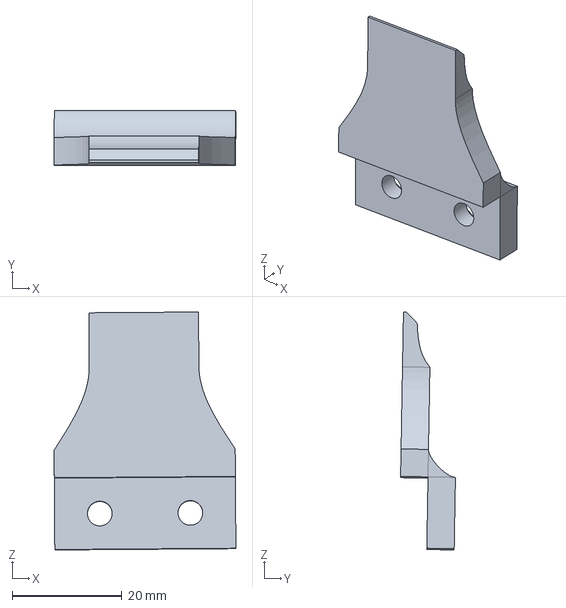
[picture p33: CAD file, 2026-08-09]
cad/exports/follower/Claw Pad.step
33.1 x 10.0 x 43.4 mm

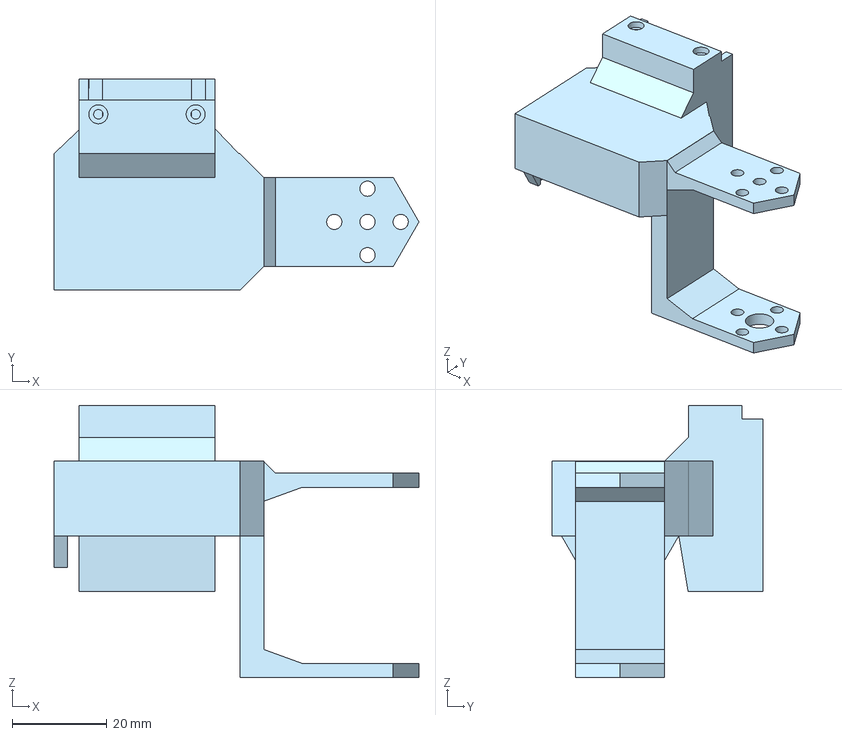
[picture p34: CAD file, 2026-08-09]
cad/exports/leader/link4.step
76.9 x 44.5 x 57.3 mm

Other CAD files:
cad/exports/leader/link3.step
cad/exports/follower/link2.step
cad/exports/follower/bottom_rack.step
cad/exports/leader/wheel.step
cad/exports/follower/link1.step
cad/exports/follower/link3.step
cad/exports/follower/link4.step
cad/exports/follower/link5.step
cad/exports/follower/pinion.step
cad/exports/leader/base.step

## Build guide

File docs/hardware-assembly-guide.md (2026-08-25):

# Hexarm — Hardware Assembly Guide

This covers fastening the printed/CAD parts to the servos, and the physical
workspace setup around the finished arms. It does not re-derive part
geometry or link-by-link fit — for that, the [Onshape assembly
(public)](https://cad.onshape.com/documents/0670dbd7fb06bb7c9bf9782d/w/e043c38067500e43503b5676/e/e17080d119308b27c44a0ee6)
is the primary reference and is detailed enough to build from directly
(leader and follower are modeled as two separate assemblies in that doc).
This guide is for the things that aren't obvious just from looking at the
CAD: which fastener goes where, build order, and — most importantly — the
physical setup constraints that affect data collection and training later.

---

## 3D Printing

All printed parts (links, bases, camera mounts, claw) were printed on a
Bambu Lab P1S with budget/generic PLA, using Bambu Studio's **Strength**
preset rather than the default profile — the extra wall/infill it adds was
worth the print-time cost given how much these parts flex and bend under
load in practice (see [postmortem #6](debugging/postmortems.md), base
tipping, and [postmortem #7](debugging/postmortems.md), servo-mount joints
bending). Printing has to happen before anything below — have a full set of
both arms' parts on hand (`cad/exports/leader/` and `cad/exports/follower/`)
before starting assembly.

---

## Before You Start

- **Assign each servo's ID before mounting it into the arm.**
  `software/low-lvl-setup/setup_servo.py` requires exactly one servo on the
  bus at a time (all servos ship at factory default ID `1` and will collide
  if powered up together) — far easier to do this with a servo sitting
  loose on the bench than after it's daisy-chained into a fully built arm.
  Target IDs: follower `1`–`6`, leader `7`–`12` (see [ADR
  0002](adr/0002-single-bus-servo-topology.md)).
- Have both STEP export sets open or printed for reference:
  `cad/exports/leader/` and `cad/exports/follower/`.

### Tools

- Phillips (crosshead) screwdriver. Exact bit size isn't critical,
  just make sure it seats fully in the screw head before applying torque,
  the M2 heads are small enough to strip if it's not fully seated.
- No thread-locker is used on any of these fasteners by choice; screws
  have held securely without loosening under the arm's motion, and
  thread-locker would make dissassembly more difficult.

---

## Fasteners (per servo)

Each STS3215 servo ships with 5× M3 and 4× M2 screws.

| Fastener | Qty per servo | Connects | Notes |
|---|---|---|---|
| M3 | 5 | The two metal horn plates on either end of the servo | One plate keys onto the output driveshaft (drives the joint); the opposite plate spins freely and is purely a support/idler bearing for the far side of the servo — don't confuse the two, only one side is driven. |
| M2 | 4 | Servo body → the printed link supporting it | Mounts the servo itself into the arm's link structure. |

---

## Assembly Order

1. Configure each servo's ID (and return delay, if not already set) one at
   a time on the bench — see [Before You Start](#before-you-start).
2. For each servo: bolt on the two M3 horn/idler plates first, then mount
   the servo body into its supporting link with the 4× M2s.
3. Build up each arm link-by-link per the Onshape assembly view. Leader and
   follower differ (leader: `base`, `crank`, `link1`–`4`, `wheel`;
   follower: `base`, `link1`–`5`, `claw`, `pinion`, top/bottom rack) — work
   from the matching arm's assembly, not the other one.
4. Repeat for the second arm.

---

## Workspace Setup — Critical for Data Collection

This matters as much as the mechanical assembly itself. After training begins,
if the captured scene changes, the trained policy may fail unpredictably.

- **Clamp/screw both arm bases securely to a table** (a foldable table is fine; 
  that's what's in use here). A free-standing base isn't enough: the arm's
  own motion generates a tipping moment that an unclamped base can't
  resist on its own, and a base that shifts throws off every joint's
  calibrated position. This is exactly the failure in [postmortem
  #6](debugging/postmortems.md) — the fix there was making the base
  clamp to the table rather than relying on its own footprint/mass.
- **Position the two arms so neither can physically reach the other** (or
  the operator) at full extension. Don't just eyeball the spacing — after
  clamping, power up each arm in `go_neutral.py --diagnostic` mode
  (hold-to-move, releases instantly) and sweep it out to its joint limits
  by hand to confirm the real reachable envelope before trusting the
  layout.
- **Once cameras are mounted and calibration/recording begins, treat the
  entire workspace as fixed** — table position, arm bases, camera mounts,
  and background. A trained policy has zero experience with a scene it
  wasn't recorded against; moving anything (even something that seems
  incidental, like an object left in frame) can degrade or break policy
  performance in ways that look nothing like a hardware fault. See the
  camera-placement research in [docs/context.md](context.md)'s Vision
  section for the related constraint on keeping the camera pose itself
  fixed.

---

## First Power-On

For a freshly assembled arm, do the first torque-on with
`go_neutral.py --diagnostic` rather than a script that drives straight to a
stored goal position. A newly mounted servo horn has no guarantee it was
seated at the exact position the software expects — a full-speed move to
an assumed neutral pose on the very first power-up could be a large,
unexpected motion. Hold-to-move lets you confirm each joint's direction and
range by hand before trusting it to move on its own.

---

## Next Steps

Once both arms are mechanically assembled and IDs are confirmed on the bus,
per-joint calibration (`software/calibration/calibrate_lerobot.py`) and
neutral-pose capture (`record_neutral.py`) come next — see
[docs/context.md](context.md) for that procedure.

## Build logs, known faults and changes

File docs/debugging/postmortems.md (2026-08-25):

# Postmortems

Consolidated log of hardware/software incidents encountered while building hexarm — each one root-caused, not just patched. Comprehensive chronology for incidents 1–2 lives in [`servo-comms-debug-log.md`](servo-comms-debug-log.md); incident 3's original handoff doc lives at `docs/context mds/lerobot-calibration-wrap-around.md`.

---

## 1. No Servo Communication At All

**Dates:** ~2026-05-17 to 2026-05-19 (~3 days) · **Severity:** Blocking

**Symptom:** Zero response from any STS3215 servo, on any host (Mac, Arduino, Raspberry Pi), any interface (USB, UART), any baud rate (9600–1,000,000). Servos powered on (red LED lit) but never replied to a ping, and never physically stiffened in response to a broadcast torque-enable.

**Investigation:** Systematically isolated the hardware path — tested across three different hosts and two different Waveshare boards and STS3215 units, ruling out a single bad component. Bypassed the SDK entirely with a raw pyserial ping to remove software as a variable. Every combination failed identically, which pointed at something common to all setups rather than any one host/interface.

**Root cause:** The Waveshare Bus Servo Adapter (A) labels its UART pins from the *host's* perspective, not the device's. Standard UART convention crosses TX↔RX between two devices; this board's silkscreen means "connect the host's TX wire to the pin labeled TX," i.e. straight-through wiring (TX→TX, RX→RX). Every wiring attempt had used the standard crossed convention.

**Fix:** Rewired straight-through (TX→TX, RX→RX, GND→GND) per the corrected understanding.

**Lesson:** Verify a third-party board's pin-labeling convention before assuming standard UART crossing. A broadcast command (ID 0xFE, no response expected) is a cheap way to test "is the data line reaching the bus at all" without needing to know a servo's ID first.

---

## 2. Intermittent Ping Failures — Two Stacked Root Causes

**Dates:** 2026-05-20 to 2026-05-25 · **Severity:** Blocking (masked as "mostly working")

**Symptom:** After incident 1's fix, pings succeeded only 15–40% of the time. Byte counts were always exactly 0/6 or 5/6 — never 1, 2, 3, or 4.

**Investigation (first pass — wrong):** Built a stress-test harness (`ping_stress.py`) that logged hundreds of ping attempts locally to CSV. The "never 1–4 bytes, only ever the first byte missing" pattern was a strong, self-consistent signal: it matched a UART framing-error theory (the half-duplex bus driver's RC turnaround time causing the first response byte to be misread as garbage while the line is still charging). Built a fix around that theory — a resync parser that over-reads by one byte to recover a dropped header — plus retry logic. This appeared to work.

**Investigation (second pass — real cause):** The "fix" from pass one caused a *new* regression: SDK calls that do multiple reads per call (like `ping()`, which does a PING + a follow-up model-number read) started failing with `COMM_RX_CORRUPT`, consistently, even after reboots and reseated connectors. A loopback test — jumpering the Pi's own TX to its own RX and trying to read back what was written — failed to echo anything. That falsified the framing-error theory outright: if the Pi couldn't hear its own transmitted bytes, the Waveshare board and servo bus were never the problem. `dmesg` and `stty -F /dev/ttyAMA0` then showed the port pinned at 115200 despite the code requesting 1,000,000 baud.

**Root cause:** A kernel serial console + `serial-getty@ttyAMA0.service` were still attached to the same UART used for the servo bus. The getty silently consumed incoming bytes before pyserial could read them, wrote login-prompt characters onto the TX line, and held the port at its console baud rate at the kernel level. This explained every symptom from pass one — the "always missing byte 1" pattern was the getty grabbing bytes from the line randomly, and "retry helps" was coincidence, not RC warm-up. On top of that, pass one's resync-parser "fix" turned out to have its own bug: reading `length+1` bytes to recover a dropped header silently stole a byte that `ping()`'s second, chained read still needed — a second, independent bug hiding behind the first.

**Fix:** Removed `console=ttyAMA0` from the kernel command line and disabled `serial-getty@ttyAMA0.service` (or, more simply, `raspi-config` → Serial Port → login shell **No**, hardware **Yes**). Reverted `port_handler.readPort()` to the stock upstream SDK implementation; moved retry/recovery logic to an outer wrapper (`_serial_utils.py`) instead of patching SDK internals.

**Lesson:** A theory that explains every observed symptom can still be wrong — the fix is a falsifying experiment, not more confirming evidence. The loopback test collapsed the whole framing-error narrative in one command. `stty` reporting a baud rate you never set is a red flag that something else owns the port; `dmesg | grep -iE "uart|serial|tty"` should be one of the first checks. Monkey-patches to shared SDK internals need to be audited across *every* call site, not just the one under test — a fix for a single-step read broke a multi-step one.

---

## 3. Encoder Wrap-Around — Negative Calibration Values

**Dates:** 2026-05-31 to 2026-06-02 · **Severity:** Blocking (calibration crash)

**Symptom:** LeRobot calibration crashed with `ValueError: Negative values are not allowed: -827` for certain joints, but not others.

**Investigation:** Streamed raw encoder positions per joint while manually sweeping each one to its physical stops. Found that some joints' physical travel arc straddles the STS3215's 12-bit encoder rollover (4095→0), while others don't. The servo's homing math (`homing_offset = 2047 − raw_mid`) worked fine for non-wrapping joints but produced a negative homed position for one stop on wrapping joints — and `write_calibration` rejects negative values for the unsigned `Min_Position_Limit` EPROM register.

**Root cause:** `Present_Position` is actually `(raw_encoder − Homing_Offset) mod 4096` — the encoder's reporting *seam* (where the value jumps 4095↔0) is not fixed to the magnet's physical zero; it sits wherever `raw = Homing_Offset`. Homing at the arc's endpoint (rather than its center) placed that seam *inside* the joint's traveled range, so one physical stop legitimately needed to report a negative position — which the unsigned EPROM field can't hold. The `-827` error was a symptom of a bad homing choice, not evidence that negative ranges are unsupported in general.

**Fix:** Homed at the arc's *midpoint* instead of an endpoint. This throws the seam exactly 2048 counts away from center — the middle of the joint's *untraveled* ("dead") gap — so any travel range under 360° never crosses it. Rewrote `calibrate_lerobot.py` around the library's own primitives in the correct order: `configure_motors()` (clears the Phase register bit so position reporting is clean single-turn mod-4096) → `set_half_turn_homings()` (homes at the measured center) → `record_ranges_of_motion()` (now records a clean, contiguous, all-positive range).

**Lesson:** SO-100/LeRobot doesn't special-case wrap-around joints — it *avoids* the seam entirely via home-at-center, so no negative EPROM write is ever needed for a physically valid joint. Understanding the seam as something that *moves* with the chosen homing offset (rather than being fixed to the magnet) was the key insight that made the fix obvious in hindsight.

---

## 4. Leader Gripper — Manual Actuation Force Breaking PLA Parts

**Dates:** started 2026-07-15 · **Severity:** Moderate

**Symptom:** During teleoperation, the leader arm's gripper servo runs torque-disabled ("limp mode") so the claw can be manipulated by hand. Rotating the gripper bars by hand under limp mode takes surprisingly high force due to the servo's internal gearbox drag, and PLA gripper parts aren't strong enough to withstand the bending moment.

**Investigation so far:**
- **Attempt 1 — thick squeeze bars:** printed two thicker bars to squeeze directly. Functional but awkward to hold while simultaneously operating the other 5 joints one-handed.
- **Attempt 2 — finger-hole attachments:** printed two finger-hole mounts that attach to the existing gripper bars, intended to give a more natural grip while leaving fingers free for the other joints. Problems:
  - The mounts flex/bend under load and go out of alignment with the claw's linear guide, which introduces friction that adds even more resistance to an already-stiff motion.
  - The finger mounts sit at a distance from the bar's pivot, creating a long lever arm — the torque this generates at the attachment point is close to snapping the PLA outright.

**Root cause:** "Limp-mode" still required significant torque, and PLA wasn't stiff enough to transmit that torque through a second lever arm without bending or snapping. 

**Fix:** Crank mechanism: rotated the servo mount and attached a crank to the shaft plate, sacrificing leader-follower link symmetry for precise, stable control of the gripper. Since the crank had no physical joint limit, normalized values were used to map a wide range of crank positions to the constrained follower claw limits. This change additionally allowed for more precise control of the follower. 

**Lesson:** When working with brittle materials such as PLA, consider which components will be subject to higher stress **before manufacturing**, especially when precision is necessary. 

---

## 5. Claw Too Small — Dropping Grasped Objects

**Dates:** started 2026-07-27 · **Severity:** Impactful but non-blocking

**Symptom:** The follower claw's jaw opening/contact geometry is undersized for the objects being grasped during teleop — grip doesn't fully secure the object, and it either snaps or slips mid-manipulation.

**Root cause:** 

**Fix:** To allow for flexibility when grasping objects and avoid snapping, two TPU claw pads were designed to fit onto the ends of the gripper arms. 

**Lesson:** When working with claw-like components, leverage materials with specific properties based on the specific payloads being manipulated. Specifically, flexible materials like TPU can be used to make a claw forgiving without sacrificing gripping capability. In sum, when mechanical precision is difficult or varied, flexible materials improve adaptability and distribute load.

---

## 6. Arm Base Instability — Bending/Tipping Under Load

**Dates:** during CAD/build assembly, resolved by 2026-08-09 · **Severity:** Blocking (assembly)

**Symptom:** The free-standing arm base bent and the arm tipped/fell over during assembly and testing.

**Investigation:** The base had been sized to support the arm's static weight while sitting still, not the tipping moments generated once the arm moves — the shoulder/base joint applies a lever-arm load that a free-standing footprint has to resist entirely through its own stiffness and mass.

**Root cause:** Static support and dynamic tip-resistance are different requirements — a base wide/heavy enough to hold the arm upright at rest can still flex or tip once the arm swings its weight around, because that introduces a moment the base's footprint alone wasn't sized against.

**Fix:** Made the base clampable to the table (rather than relying on the base's own footprint and mass for stability), converting the table itself into part of the base's effective support.

**Lesson:** Inertia is an important design consideration. Where possible, use fasteners (screws, bolts, clamps) to improve rigidity instead of relying on friction, and design around worst-case conditions.

---

## 7. Servo-Mount Joint Bending — PLA Screw Points Undersized

**Dates:** during CAD/build assembly, resolved by 2026-08-09 · **Severity:** Moderate

**Symptom:** Printed links bent under load, specifically at the joints, at the point where the PLA part screws into the servo horn.

**Investigation:** The bending was localized to the fastener bosses at each servo attachment, not distributed along the link, pointing at the screw point itself rather than the part's general cross-section as the weak spot.

**Root cause:** The screw-in boss where a link bolts to a servo horn is a stress concentration; a smaller, thinner feature than the rest of the link, carrying the full joint load through a small attachment area. Sizing wall thickness for the link overall didn't account for this local feature needing its own margin.

**Fix:** Thickened the links specifically at the servo screw-in points (not a uniform thickness increase across the whole part).

**Lesson:** Fastener attachment points on a printed part are a distinct sizing problem from the part's general wall thickness — treat them as their own local stress concentration and reinforce them directly. As a general rule of thumb, design attachment points with care, using ANSYS to determine high-stress areas if not apparent.

---

## 8. Phantom Episodes — Silent Data Loss From a Resolution Mismatch on `--resume`

**Dates:** 2026-08-10 · **Severity:** High (unrecoverable data loss)

**Symptom:** After a `record_dataset.py --resume` session that appeared to complete normally (no errors, no crash), `meta/info.json` reported `total_episodes=5` / `total_frames=3447`, but the actual per-episode data — `data/chunk-000/file-000.parquet`, the video files, and `meta/episodes/...parquet` — only ever had 3 real episodes / 2268 frames. Two full episodes' worth of counters existed with no data behind them.

**Investigation:** Confirmed via direct inspection that `info.json`'s totals didn't match row counts in the actual parquet/video files, then cross-checked file mtimes: `info.json` had been touched at 15:28:40, but the real data files' last-touched time was 14:45:55 — matching only the original recording session, not the later `--resume` session that supposedly added 2 more episodes. That pinned the corruption to something in the resume path specifically, not the original recording.

**Root cause:** Earlier the same session, `record_dataset.py` had been changed to downscale newly-recorded frames to 640×400 (for faster video encoding — see the video-encode speed investigation) via unconditional `RECORD_WIDTH`/`RECORD_HEIGHT` constants. That change only accounted for *new* datasets. `hexarm/pick_and_place` had already been created earlier at the camera's native 1280×800, so its on-disk schema (`dataset.features[...]["shape"]`) was permanently locked at 1280×800. Resuming it with the new code wrote 640×400 frames into an 1280×800-schema dataset. LeRobot's dataset writer advances its internal episode counter *before* the shape-mismatched image/video data actually fails to merge — so the failure was silent from the operator's side: no exception, no warning, just counters that quietly went wrong. By the time this was discovered, the raw per-tick frames for both phantom episodes had already been cleaned up as part of the (apparently successful) save flow, so the underlying recordings were gone — not just mislabeled.

**Fix:** Replaced the unconditional `RECORD_WIDTH`/`RECORD_HEIGHT` constants in the recording tick loop with a `record_sizes` dict derived dynamically from the dataset's *own* declared feature shape right after `create()`/`resume()` (`dataset.features[f"observation.images.{name}"]["shape"]`), so recording always matches whatever resolution that specific dataset is actually locked at — 1280×800 for an old dataset, 640×400 for a freshly-created one — instead of assuming one fixed resolution applies everywhere. `meta/info.json`'s counters were hand-repaired back to the true state (5→3 episodes, 3447→2268 frames), and the orphaned frame directories for the two phantom episodes were deleted. Going forward, datasets that need the faster resolution are created fresh under a new `repo_id` (e.g. `pick_and_place_v2`) rather than resized in place — resolution is schema-locked for the lifetime of a dataset, there's no in-place "upgrade."

**Lesson:** Any per-recording constant that a script assumes applies globally (resolution, feature shape, etc.) needs to be checked against the specific artifact being *resumed*, not just the artifact being *created* — `create()` and `resume()` are not symmetric, and a fix validated against "start fresh" doesn't automatically hold for "continue existing." Also: a library that advances a counter before validating the data behind it turns a hard failure into a silent one — when writing anything that resembles "reserve a slot, then fill it," validate before incrementing, not after, or a downstream failure corrupts bookkeeping instead of raising.

---

## 9. Jetson Hard-Freezes During Local ACT Training — RAM Exhaustion With No Swap

**Dates:** 2026-08-11 to 2026-08-13 · **Severity:** Blocking (required a physical power cycle both times to free ram)

**Symptom:** The Jetson hard-froze twice while running `lerobot-train`'s local ACT benchmark (`--steps=300` smoke test against `hexarm/pick_and_place_v2`) — SSH dead, no console response, requiring a physical power cycle both times. Neither crash left a kernel panic, an OOM-killer log line, or any graceful-shutdown trace; the system journal simply stopped mid-boot with nothing further.

**Investigation:** The first crash (2026-08-11, 16:53:23) happened mid-conversation with Claude Code, but the actual crashing command wasn't in that session's own tool-call history — it had been run manually in a separate terminal and only pasted back as output. Recovering the literal command meant grepping the raw Claude Code session JSONL transcripts under `~/.claude/projects/` and cross-referencing timestamps. `journalctl -b -1` on that first crash showed the last kernel message before the log went dark was `nvme nvme0: I/O tag 464 (41d0) QID 1 timeout, completion polled` — pointing at NVMe power delivery as the likely trigger, especially combined with the board's factory-default 25W `nvpmodel` mode. That theory drove a first mitigation attempt, but wasn't confirmed before a second, deliberate repro was set up: `tegrastats` logging and the training command's own stdout both redirected to the **eMMC root** (`/home`, not `/data`) at high resolution, specifically so telemetry would survive even if the NVMe browned out again. The second crash reproduced in the same command's first-step warmup window, but the surviving telemetry told a different story: RAM at 7280–7292MB of the board's 7486MB total (97–98% full) with **swap at 0B**, CPU/GPU utilization near-idle for ~28 seconds (stuck, not computing), then both `tegrastats` and the system journal going silent together — no NVMe timeout this time. That ruled out power delivery as the primary mechanism (the first crash's NVMe timeout was real but a downstream symptom, not the root cause) and pointed at memory exhaustion instead.

**Root cause:** The board has 7.3GB of usable unified CPU/GPU memory and zero swap configured. During the dataloader's prefetch warmup (`prefetch_factor=4`, decoding camera video frames into batches ahead of the training loop) on top of the baseline RAM already held by the desktop GUI session (gdm/gnome-shell/PackageKit — this is a full Ubuntu desktop image, not headless), the board hit close to 100% memory utilization with nowhere to go. `systemd-oomd` — the userspace OOM killer that should have stepped in first — was silently disabled the whole time: its unit requires `/proc/pressure/memory`, which this kernel doesn't expose, so the condition check failed and it never armed. With no swap and no working OOM protection, the kernel had no graceful way out of the pressure spike and hard-locked instead of killing/throttling the offending process.

**Fix:** Installed `zram-tools` for compressed-RAM swap (chosen over a disk-backed swapfile specifically to avoid adding NVMe/eMMC I/O load at the exact moment the system is already under stress). The package's default config failed outright — `ALGO` defaults to `lz4`, which this Tegra kernel's zram driver doesn't support (`cat /sys/block/zram0/comp_algorithm` only lists `lzo`, `lzo-rle`, `zstd`) — fixed with `ALGO=zstd` in `/etc/default/zramswap`. Its other default, a flat `SIZE=256` (MiB), was also far too small against a multi-GB spike; fixed with `PERCENT=50` instead (~3.7GB — `PERCENT` overrides `SIZE`). Verified by re-running the identical 300-step benchmark with telemetry watching again: RAM hit the same ~97% ceiling, but this time zram absorbed ~1.4GB into swap at peak instead of the kernel hitting a wall — training pushed through the same warmup window that killed it twice before, completed all 300 steps (loss 28.07 → 3.00, confirming real learning, not just non-crashing), and the checkpoint saved cleanly to disk.

**Lesson:** A crash that leaves nothing behind — no panic, no OOM-kill message, no core dump — doesn't mean there's nothing to find; it means the evidence has to be captured *during* a live reproduction, written somewhere that survives the failure mode under test (eMMC root, not the drive suspected of failing). The first crash's NVMe timeout was a real, reproducible-looking signature that still pointed at the wrong root cause — only a second, instrumented repro separated symptom from mechanism. Separately: on an 8GB unified-memory board, swap isn't optional for GPU training workloads, and `systemd-oomd`'s silent dependency on `/proc/pressure/memory` (present on many kernels, absent on this one) means "the OOM killer will handle it" isn't a safe assumption without checking first.

---

## 10. First Hardware Policy Run — Claw Grazing the Block, Near-Clipping the Bowl Lip

**Dates:** First run (2026-08-19) · **Severity:** High (near-miss, no actual damage)

**Symptom:** First physical run of the trained policy (`act_pick_and_place_v2`, 25,000-step checkpoint, via `run_policy.py`'s dead-man's-switch mode) completed the pick-and-place task successfully, but with thin real-world margins in two places: (1) during the pick, the claw would sometimes graze the block while closing around it — if contact had been harder, it risked breaking the claw; (2) during the place, the trajectory toward the bowl would often pass just over the bowl's top lip, with little clearance to spare.

**Investigation:** Caught by eye during the run itself, under the dead-man's-switch (SPACE held in short bursts, per the script's own guidance) — not by any automated check. Notably, nothing in the policy's offline eval numbers predicted this: L1 loss was 0.0942 at 25k, monotonically decreasing across all 5 checkpoints with no sign of overfitting (see the 2026-08-14 session log). That number measures how faithfully the policy reproduces the *demonstrated* trajectories, not how much clearance those trajectories leave from real-world contact — a policy can nail its training objective and still have no margin for error.

**Root cause:** The policy faithfully reproduced what was demonstrated in `pick_and_place_v2` — and those demonstrations themselves had tight margins: the leader-arm claw wasn't opened much wider than the block during approach, and the drop-off motion passed close over the bowl's rim by habit, not by design. Imitation learning has no built-in notion of "safety margin" beyond what's in the data; a policy trained on close-but-successful demonstrations reproduces those same close calls every time, minus the human reflexes that would normally catch a bad attempt.

**Fix:** Re-recorded a new 50-episode dataset, `hexarm/pick_and_place_v3` (2026-08-20), demonstrating the same task with two deliberate changes: opening the claw wider by default before closing on the block, and going deliberately higher over the bowl's lip during the drop-off. Retrained ACT from scratch on the new dataset — 30,000 steps (up from 25,000), all other hyperparameters unchanged (chunk_size/n_action_steps/kl_weight identical to the v2 run). Training completed 2026-08-21 04:56; see the session log for checkpoint eval results.

**Lesson:** An imitation-learning policy is only as cautious as its demonstrations. Offline loss confirms the policy learned the demonstrated behavior faithfully — it says nothing about whether that behavior had adequate real-world margin. When the hardware being controlled is fragile (this project's PLA claw, already an open concern per postmortems #4/#5) or the workspace has hard edges, demonstrate with margins deliberately wider than a human teleoperator would think necessary. The policy will reproduce your habits, including your close calls, on every attempt rather than just the one where you got lucky.

**Verification (2026-08-21):** Ran the v3 checkpoint on hardware via `run_policy.py` (dead-man's-switch, SPACE held in bursts) — 3 successful pick-and-place completions. Both margins confirmed improved: claw clearance around the block on pick and clearance over the bowl's lip on drop-off were both noticeably wider, no grazing or near-clipping observed across the 3 runs. Separately, some runs failed to pick up the block at all due to camera-coverage blind spots (a different failure mode, not a margin/clearance issue) — noted as a known limitation, not being pursued further (no additional training planned).

---

*Have a new issue in progress? Add a new `## N. Title` section above using the same template — even a partially-solved entry (Symptom + Investigation so far) is useful; fill in Root Cause / Fix / Lesson once resolved.*

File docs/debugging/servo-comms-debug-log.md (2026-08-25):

# Servo Communication Debug Log

**Hardware:** FEETECH STS3215 × 12, Waveshare Bus Servo Adapter (A) × 2, Raspberry Pi Zero 2W  
**Duration:** ~3 days  
**Resolution date:** 2026-05-19  
**Root cause:** Incorrect UART wiring convention (crossed instead of straight-through)

---

## Problem Statement

After assembling the hexarm hardware stack, no serial communication could be established with any STS3215 servo from any host device. Servos powered on (red LED lit), but returned zero bytes in response to ping packets, and showed no physical response to broadcast torque commands.

---

## System Architecture

```
Host (Mac / Arduino / Pi)
        ↓  full-duplex UART (TX + RX)
Waveshare Bus Servo Adapter (A)
        ↓  half-duplex TTL serial bus
STS3215 servo(s) — daisy-chained, each with unique ID
```

The Waveshare board handles half-duplex direction switching internally. The host sees a normal full-duplex UART interface; the board drives the servo bus in one direction at a time.

---

## Debugging Chronology

### Phase 1 — Mac via USB (USB-Servo mode)

**Setup:** Mac → USB-C → Waveshare board (USB-Servo mode) → JST → STS3215  
**Tools:** `ping_one.py` (scservo_sdk), `raw_ping.py` (pure pyserial), `baud_scan.py`

**What was tried:**
- `ping_one.py` with scservo_sdk → "There is no status packet" for all IDs
- Official Waveshare `sms_sts/ping.py` example → same result
- `raw_ping.py` bypassing SDK entirely → "No bytes received"
- All supported baud rates: 9600 / 19200 / 38400 / 57600 / 115200 / 250000 / 500000 / 1000000
- IDs 1–20 at every baud rate
- Broadcast torque enable (ID 0xFE) → no physical stiffening at any baud
- Both `/dev/tty.*` and `/dev/cu.*` port prefixes on macOS

**What was ruled out:**
- Echo fix: added `ser.read()` after writes thinking board echoed TX bytes back — it doesn't. The board handles half-duplex in hardware with no echo. Fix reverted; protocol_packet_handler.py left stock.
- Wrong SDK class: `sms_sts` is correct for STS3215 (not `scscl`)
- tty vs cu: no difference in outcome

**Suspected causes (all wrong):**
- Mac USB CDC driver silently dropping writes
- Board data line not passing signal to servo bus
- Servo bricked or in fault state

---

### Phase 2 — Arduino via UART (direct to servo)

**Setup:** Arduino → 1kΩ resistor half-duplex bus → STS3215 directly  
**Result:** No response

**Note:** Arduino Uno at 16MHz cannot accurately generate 1Mbps baud — the hardware UART's divisor doesn't divide evenly to 1,000,000. This makes the Arduino test inconclusive. Communication failure here is expected and does not confirm or deny servo health.

---

### Phase 3 — Raspberry Pi Zero 2W via UART (UART-Servo mode)

**Setup:** Pi GPIO UART → Waveshare board (UART-Servo mode) → JST → STS3215

#### Pi setup required:

1. **OS:** Ubuntu 24.04 Server (fresh flash via Raspberry Pi Imager)
2. **SSH:** Configured WiFi credentials in Raspberry Pi Imager; accessed via `ssh ekapi@eka-pi02w.local`
3. **Free the PL011 hardware UART from Bluetooth:**
   ```bash
   echo "dtoverlay=disable-bt" | sudo tee -a /boot/firmware/config.txt
   echo "enable_uart=1" | sudo tee -a /boot/firmware/config.txt
   sudo reboot
   ```
   After reboot: `/dev/ttyAMA0` appears on GPIO 14 (TX) and GPIO 15 (RX)
4. **Add user to dialout group** (for UART access without sudo):
   ```bash
   sudo usermod -a -G dialout ekapi
   sudo reboot
   ```
5. **Python environment:**
   ```bash
   sudo apt install python3.12-venv -y
   cd ~/hexarm
   python3 -m venv .venv
   source .venv/bin/activate
   pip install pyserial
   ```

#### First wiring attempt (WRONG):

Wired Pi TX → Board RX, Pi RX → Board TX (standard UART crossing convention).

**Result:** No bytes received. Identical to all previous tests.

Tested two different Waveshare boards and two different STS3215 servos — all with the same result. At this point, hardware failure was strongly suspected.

#### Root cause discovered:

A Waveshare documentation search revealed the correct wiring for the Bus Servo Adapter (A) in UART-Servo mode:

> **"the connection must be RX-RX, TX-TX"**

The board labels its UART pins **from the host's perspective** — the pin labeled TX is where the host's TX wire connects, not where the board transmits. This is the **opposite of the standard UART labeling convention**, where a device's TX pin is where it transmits and the host must connect its RX.

#### Corrected wiring:

| Pi GPIO | Board Pin |
|---|---|
| GPIO 14 (TX) | TX |
| GPIO 15 (RX) | RX |
| GND | GND |

#### Result after rewiring:

```
$ python3 baud_scan.py --port /dev/ttyAMA0

--- Baud: 1000000 ---
  *** GOT RESPONSE from ID 1: FC
  Done (no responses at 1000000)

Scan complete.
```

**Servo confirmed alive at 1Mbps, ID=1 (factory defaults intact).**

---

## Root Cause Analysis

**The Waveshare Bus Servo Adapter (A) uses non-standard UART pin labeling.**

On a typical UART device:
- The device's **TX** pin is where it **transmits** → host connects its **RX** here
- The device's **RX** pin is where it **receives** → host connects its **TX** here
- Result: wires are crossed (TX↔RX)

On the Waveshare Bus Servo Adapter (A):
- The **TX** pin means "connect the host's TX here"
- The **RX** pin means "connect the host's RX here"
- Result: wires are straight-through (TX↔TX, RX↔RX)

This convention is used on some boards where the designer labeled the connector from the system integrator's perspective rather than the device's perspective. It is not documented prominently on the Waveshare wiki.

**Every other aspect of the setup was correct.** The SDK, baud rate, packet format, servo IDs, board power, servo power, and OS configuration were all fine. Three days of debugging were caused by two wires being swapped.

---

## Lessons Learned

1. **Verify pin labeling convention before assuming standard UART crossing.** When using third-party adapter boards, always check whether UART pins are labeled from the device's or the host's perspective.

2. **Broadcast commands are a strong diagnostic tool.** Broadcast torque enable (ID 0xFE) requires no ID knowledge and no response — if servos don't physically stiffen, the data line isn't reaching them.

3. **Isolate the hardware path systematically.** Testing across multiple hosts (Mac, Arduino, Pi) and multiple interfaces (USB, UART) helped rule out software and driver issues — but the common failure point (the wiring convention) affected all of them equally.

4. **Arduino is unreliable for 1Mbps UART.** At 16MHz, the hardware UART cannot accurately generate 1Mbps. Do not use Arduino results as ground truth for high-baud servo communication.

5. **`raw_ping.py` is the right first diagnostic.** Bypassing the SDK removes one entire layer of potential failure. Always start with the most direct hardware test.

---

## Working Configuration Reference

```
Pi Zero 2W (Ubuntu 24.04)
  GPIO 14 (TX) ────────────────── TX  ┐
  GPIO 15 (RX) ────────────────── RX  │  Waveshare Bus Servo Adapter (A)
  GND          ────────────────── GND ┘  (switch: UART-Servo)
                                          │
                                       JST connector
                                          │
                                       STS3215 servo
                                       (ID=1, 1Mbps, factory defaults)

UART device: /dev/ttyAMA0
Baud rate:   1,000,000
```

---

## Phase 4 — Intermittent Response Failures (2026-05-20)

**Symptom:** After basic communication was established (Phase 3), pinging a servo produced inconsistent byte counts: always 0/6 or 5/6, **never 1–4**. Running `raw_ping.py` manually ~100 times showed a loose pattern of 2–3 failures followed by a success.

---

### Data Collection

Wrote `ping_stress.py` — a stress-test script that pings a servo N times and logs every result (timestamp, byte count, hex bytes) to CSV. Two modes: `--mode reopen` (re-opens serial port each ping) and `--mode keepopen` (port stays open).

Results at 1Mbps over ~100 pings each:

| Mode | OK (6/6) | MISS (0/6) | PARTIAL (5/6) |
|---|---|---|---|
| reopen | ~14% | ~10% | ~76% |
| keepopen | ~30% | ~30% | ~40% |

Key observations:
- **PARTIAL was always exactly 5/6** — the missing byte was always the first one (0xFF)
- **Never 1, 2, 3, or 4 bytes** across hundreds of attempts
- keepopen mode had more MISSes (0/6) than reopen

---

### Hypothesis Generation

The "never 1–4" pattern is a strong constraint. If the cause were:
- Timing / return delay → you'd get partial responses cut off anywhere in the packet
- Loose wire → random byte counts, possible mid-packet dropout
- VMIN=0 read() race → 0 bytes only (not 5)

The only consistent explanation for 0/5/6 with nothing in between: **only the first byte is vulnerable, and all subsequent bytes arrive as an indivisible block.**

---

### Root Cause: UART Framing Error

At the TX→RX bus turnaround on a half-duplex bus, the servo's line driver must pull the bus line back to idle-high before sending the response. This takes a finite time determined by the RC time constant: **τ = R_driver × C_bus**, where R is the driver's output impedance and C is the total parasitic capacitance of the wiring, connectors, and pins.

During this rise time, the PL011 UART sees the line sitting low. It interprets the falling edge (TX→idle→response) as a start bit. It then clocks in 8 "data" bits while the line is still charging — garbage data. At the end of the byte, when it checks the stop bit (expected high), it may find the line low → **framing error**.

The Linux tty layer, running under its default `IGNPAR` configuration, **silently discards** framing-errored bytes. No signal is sent to userspace. The discarded byte is gone.

Because only the **first byte of the response** is at the turnaround boundary, and all remaining bytes are transmitted contiguously (no gap between them), only the first byte is ever affected. This perfectly explains the 0/5/6 distribution.

The 0/6 case: occasionally the framing error hits the **outgoing ping packet's** first byte instead, corrupting the command. The servo rejects the malformed packet and sends no response.

**Why retry works:** After the first transmission, the line driver's gate capacitances are partially charged and the driver re-enables faster on the next attempt. This is an RC capacitance effect — the driver is "warm" — not a thermal effect. On a DIY setup with hand-soldered headers and longer-than-spec wire runs, parasitic capacitance is higher than on a proper PCB, making this effect more pronounced.

**What doesn't help:**
- **Return delay (reg 7):** adds silence *before* the response, but the framing transient is locked to byte 1 of the response regardless of how long the bus was silent before it
- **Baud rate reduction (250kbps tested):** the RC time constant is set by hardware capacitance, not by bit timing; a slower baud rate doesn't shrink the transient

---

### VMIN/VTIME Discovery

A separate issue: pyserial sets `VMIN=0 VTIME=0` on `serial.Serial()` open, and these terminal settings **persist after `close()`**. With `VMIN=0`, a `read(n)` call returns immediately with 0 bytes if nothing has arrived yet — it doesn't block. This caused `raw_ping.py` run-to-run inconsistency that was mistaken for a hardware issue.

**Fix:** After opening the port, call `termios.tcsetattr()` to set `VMIN=n` (where n = expected response length). This makes `read(n)` block until n bytes are available, eliminating the race condition.

```python
def set_vmin(ser, vmin, vtime=0):
    fd = ser.fileno()
    attrs = termios.tcgetattr(fd)
    attrs[6][termios.VMIN]  = vmin
    attrs[6][termios.VTIME] = vtime
    termios.tcsetattr(fd, termios.TCSANOW, attrs)
```

---

### Fix Implemented

**1. Resync parser** (added to `scservo_sdk/port_handler.py:readPort()` and `control/raw_ping.py:parse_response()`):

- Read `length+1` bytes (one extra to absorb the potential dropped first byte)
- Search for `FF FF` header → clean case, return `buf[i:i+length]`
- If not found, search for lone `FF` → the first 0xFF was dropped; prepend a synthetic 0xFF to reconstruct the original packet
- Validate with checksum: `~(ID + LEN + ERR) & 0xFF`

```python
# Clean case
for i in range(len(buf) - 1):
    if buf[i] == 0xFF and buf[i + 1] == 0xFF:
        return bytes(buf[i:i + length])

# Lone FF — first 0xFF dropped, reconstruct
for i in range(len(buf)):
    if buf[i] == 0xFF:
        return bytes(bytearray([0xFF]) + buf[i:i + length - 1])
```

**2. Retry on empty response** (`raw_ping.py`, MAX_RETRIES=2):

```python
for attempt in range(1, MAX_RETRIES + 2):
    ser.reset_input_buffer()
    ser.write(pkt)
    raw = ser.read(PING_RESPONSE_LEN)
    if raw:
        break
```

**Result:** Near-100% reliable communication after fix. Occasional 0/6 (cold start) resolves on first retry.

---

### Servo ID Assignment (2026-05-20)

All 12 STS3215 servos assigned unique IDs using `setup_servo.py` with the `--force` flag (broadcast write, no ACK):

```bash
# For each servo (one at a time, factory default ID=1):
python3 software/control/setup_servo.py --new-id <X> --return-delay 100 --force
python3 software/control/raw_ping.py --id <X>   # verify
```

| Arm | Servo | ID | Joint |
|---|---|---|---|
| Leader | Base | 1 | — |
| Leader | — | 2 | — |
| Leader | — | 3 | — |
| Leader | — | 4 | — |
| Leader | — | 5 | — |
| Leader | Tip | 6 | — |
| Follower | Base | 7 | — |
| Follower | — | 8 | — |
| Follower | — | 9 | — |
| Follower | — | 10 | — |
| Follower | — | 11 | — |
| Follower | Tip | 12 | — |

Return delay set to 100 units (200µs) for all servos.

**Critical note about `--force` mode:** `--force` uses broadcast ID (0xFE) and skips ACK checking. Baud rate writes via `--force` write to SRAM — the EPROM only reloads on power cycle. Always specify `--baud <current_servo_baud>` when communicating at a non-default baud rate, e.g.:
```bash
python3 setup_servo.py --current-id 9 --new-baud 1000000 --force --baud 250000
```

---

### Additional Files

- `software/control/baud_scan.py` — scans all baud rates × IDs 1–20; useful when servo baud rate is unknown
- `software/control/ping_stress.py` — stress-test script; CSV output; `--mode reopen` or `--mode keepopen`
- **Note:** test CSV files (`reopen.csv`, `keepopen.csv`, `ping_stress_keepopen.csv`) had been committed to the repo despite a `.gitignore` rule that didn't actually match their path (`software/control/*.csv` instead of `software/low-lvl-setup/*.csv`) — the pattern was corrected; the already-tracked files are still pending removal

---

### Lessons Learned (Phase 4)

1. **The byte count distribution is a strong diagnostic signal.** "Never 1–4 bytes" immediately rules out timing and loose-wire hypotheses and points to a per-byte mechanism at a fixed boundary.

2. **VMIN=0 is a silent foot-gun.** pyserial's default terminal settings cause `read()` to be non-blocking. Set VMIN explicitly after opening the port on any Pi UART project.

3. **Resync parsers beat return delay tuning.** Return delay cannot fix a framing error because the transient is physically welded to byte 1. A software resync parser handles it transparently without any hardware changes.

4. **RC warm-up explains retry success.** The line driver charges faster on retry because the parasitic capacitance is already partially charged. This is more pronounced on DIY wiring than a production PCB.

5. **port_handler.py is modified — do not replace with stock version.** The resync parser lives in `readPort()`. Replacing it with the upstream SDK would re-introduce the framing error.

> **2026-05-25 update — lesson #5 above is wrong.** Phase 5 below revealed the framing-error narrative was misdiagnosed. The resync logic in `port_handler.readPort()` was reverted to the SDK original. Reasoning preserved here for context; refer to Phase 5 for the corrected understanding.

---

## Phase 5 — SDK Path Regression and the Real Root Cause (2026-05-25)

**Symptom:** With the Phase 4 fixes in place, `raw_ping.py` worked but every SDK-based script (`ping_one.py`, `calibrate.py`, `setup_servo.py`) failed with `COMM_RX_TIMEOUT` or `COMM_RX_CORRUPT`. The bug was sticky — survived reboots, survived re-seating connectors, survived `port_handler.py` edits.

This phase reframed Phase 4 entirely. The framing-error theory turned out to be wrong. Two separate problems were stacked, and one was masking the other.

---

### Step 1 — Refactor for sharing (`_serial_utils.py`)

To stop duplicating the same setup boilerplate across `ping_one.py`, `setup_servo.py`, `calibrate.py`, the code was consolidated into `software/control/_serial_utils.py`:

- `set_vmin(ser, vmin=1)` — termios fix from Phase 4
- `open_sdk_port(port, baud)` → `(port_handler, st)` — handles PortHandler boilerplate plus VMIN
- `ping_with_retry(st, id)` / `read_pos_with_retry(st, id)` / `write_byte_with_retry(st, id, addr, val)` — wrap SDK calls with a small retry budget

Also fixed: `port_handler.setupPort()` was opening pyserial with `timeout=0`, which sets `O_NONBLOCK` on the fd and **overrides any VMIN setting at the kernel level**. Changed to `timeout=0.1`, which makes pyserial use a `select()`-based timeout and lets VMIN actually take effect.

**Result:** No change. SDK path still failed.

---

### Step 2 — Diagnostic script (`sdk_diag.py`)

Built a diagnostic comparing four ping patterns against the same servo back-to-back:

| Variant | Description |
|---|---|
| A. RAW | Verbatim `raw_ping.py` — VMIN=6, single `ser.read(6)` |
| B. VMIN1 | Same as A but VMIN=1 |
| C. LOOP | VMIN=1 + `ser.read(1)` × 6 (the SDK's read pattern) |
| D. SDK | Full PortHandler + `sms_sts.ping()` stack |

First run results were unexpected: **every variant returned 0 bytes**, including A (which had worked manually moments before).

```
A. RAW   (VMIN=6, read(6)): 0/5
B. VMIN1 (VMIN=1, read(6)): 0/5
C. LOOP  (VMIN=1, read(1) x 6): 0/5
D. SDK   (PortHandler.ping): 0/5
```

This was the moment the framing-error theory started falling apart — if RC turnaround were the issue, raw_ping wouldn't have been intermittently working all session.

---

### Step 3 — Triage: power cycle, reseat, reboot, loopback

Suspecting hardware fault:

1. Power-cycled Waveshare board → no change
2. Reseated JST-PH and Dupont connectors → no change
3. Rebooted Pi → no change
4. **Bypassed Waveshare entirely**: jumpered Pi GPIO 14 (TX) directly to GPIO 15 (RX) with a Dupont wire and wrote three bytes, expected to see them echo back:

   ```python
   ser = serial.Serial('/dev/ttyAMA0', 1000000, timeout=0.1)
   ser.write(b'\xAA\xBB\xCC')
   time.sleep(0.05)
   print(ser.read(10).hex())   # Got: '' (empty)
   ```

The Pi couldn't echo its own bytes through its own UART. That eliminated the Waveshare, the servo, and the bus wiring as suspects. The problem had to be on the Pi side.

---

### Step 4 — The actual root cause

Running:

```bash
sudo dmesg | grep -iE "uart|serial|tty(AMA|S)"
```

revealed:

```
Kernel command line: ... console=ttyAMA0,115200 ...
[    1.871269] 3f201000.serial: ttyAMA0 ... is a PL011 rev2
[    1.873146] printk: legacy console [ttyAMA0] enabled
[   12.968559] systemd[1]: Expecting device dev-ttyAMA0.device - /dev/ttyAMA0...
```

And:

```bash
stty -F /dev/ttyAMA0 -a | head -1
# speed 115200 baud; rows 24; columns 80; ...
```

`stty` reported the port speed as **115200**, even though every Python script in the project was setting it to 1,000,000. The PL011 was being held at 115200 because **a kernel serial console + `serial-getty@ttyAMA0.service` were running on `/dev/ttyAMA0`**.

A getty/console on the same UART:

- **Consumes incoming bytes** before pyserial's `read()` can see them
- **Writes login prompt characters out the TX line** between reads, putting noise on the servo bus
- **Holds the port at its console baud (115200)** at the kernel level — Python's `setBaudRate(1000000)` had been silently fighting this the whole time

This single setting alone explained **every confusing symptom of Phase 4**:
- The "5/6, never 1–4" distribution → getty was occasionally swallowing the leading 0xFF
- The "retry works because the bus is warm" effect → coincidence; gettys are non-deterministic about which bytes they grab
- The bus randomly going silent → getty fully active, eating everything
- The loopback failure → getty consumed the test bytes before pyserial read them

---

### Step 5 — The fix

Two changes on the Pi:

1. **Remove the serial console** from the kernel command line. Edit `/boot/firmware/cmdline.txt` and delete `console=serial0,115200 ` (note: `serial0` is a symlink to `ttyAMA0` here because `disable-bt` routed PL011 to GPIO). The remaining `console=tty1` is fine — it's the virtual console for HDMI/log output, unrelated to the GPIO UART.

2. **Disable serial-getty:**
   ```bash
   sudo systemctl disable --now serial-getty@ttyAMA0.service
   sudo systemctl disable --now serial-getty@serial0.service
   sudo reboot
   ```

Verify after reboot:

```bash
cat /proc/cmdline | grep -o "console=[^ ]*"
# Should output:  console=tty1  (only)

stty -F /dev/ttyAMA0 -a | head -1
# Should NOT be locked to 115200 anymore
```

Easier alternative for the future: `sudo raspi-config` → Interface Options → Serial Port → login shell **NO**, hardware **YES**.

---

### Step 6 — Re-running `sdk_diag.py`

After the reboot, the diagnostic told a completely different story:

```
A. RAW   (VMIN=6, read(6)): 5/5    dt = 0.4ms
B. VMIN1 (VMIN=1, read(6)): 5/5    dt = 0.4ms
C. LOOP  (VMIN=1, read(1)x6 loop): 5/5    dt = 603ms   ← see below
D. SDK   (PortHandler.ping): 0/5   result = COMM_RX_CORRUPT, dt = 1208ms
```

**Three things to extract:**

1. **All read patterns worked cleanly.** Every variant returned a 6/6 response (`FF FF 02 02 00 FB`). Importantly, **no 5/6 cases appeared** — strong evidence that the "framing error at RC turnaround" theory of Phase 4 was misdiagnosis. The "missing first byte" pattern was getty interference all along.

2. **The read(1)-loop (variant C) was 1500× slower than the single-read variants.** That's because the patched `port_handler.readPort()` was set to read `length+1` bytes (`target = 7`) to "absorb a dropped leading byte." For a clean 6-byte response, there is no 7th byte — so the loop burned the full 600ms deadline waiting for it.

3. **The SDK variant (D) took exactly 2× the loop time (1208ms) and returned -7 (COMM_RX_CORRUPT).** That's the signature of `ping()` doing **two** transactions: the PING (succeeds, ~600ms) plus a follow-up READ of the model-number register at address 3 (corrupts, ~600ms).

---

### Step 7 — The SDK byte-stealing bug

Tracing the second transaction inside `ping()`:

1. Servo response: `FF FF 02 04 00 09 00 CHK` (8 bytes — 2-byte model number)
2. SDK calls `port_handler.readPort(6)` (initial `wait_length - rx_length = 6 - 0`)
3. Custom `readPort` sets `target = 7` and reads 7 bytes from the kernel: `[FF FF 02 04 00 09 00]`
4. Resync finds `FF FF` at offset 0, returns `buf[0:length] = buf[0:6]` — **the 7th byte (`00`) is silently dropped on the floor**
5. SDK's `rxPacket` extends `rxpacket` to 6 bytes, sees `rxpacket[PKT_LENGTH] = 0x04`, recalculates `wait_length = 4 + 3 + 1 = 8`, loops back to `readPort(2)`
6. Kernel buffer only has 1 byte left (the `CHK`) — the other needed byte (`00`) was consumed by step 3 and then thrown away
7. After another 600ms wait, `rxpacket` has 7 bytes, `wait_length = 8`, `isPacketTimeout` fires → `COMM_RX_CORRUPT`

**The "read length+1 to absorb a dropped byte" pattern is broken for any multi-transaction SDK call.** It works for single-shot reads (`ReadPos`, the first half of `ping()`), but `ping()` itself does two reads back-to-back and the stolen byte was the data the second read needed.

---

### Step 8 — Fix

Reverted `port_handler.readPort()` to the original SDK implementation:

```python
def readPort(self, length):
    if sys.version_info > (3, 0):
        return self.ser.read(length)
    else:
        return [ord(ch) for ch in self.ser.read(length)]
```

With the getty gone, framing errors at the bus turnaround are no longer observed. If they ever reappear (different hardware, longer cabling), the right place to handle them is at the SDK-call level — via the existing `ping_with_retry` / `read_pos_with_retry` / `write_byte_with_retry` wrappers in `_serial_utils.py` — not by stealing bytes in `readPort`.

Re-running `sdk_diag.py`:

```
A. RAW   (VMIN=6, read(6)): 5/5    dt = 0.4ms
B. VMIN1 (VMIN=1, read(6)): 5/5    dt = 0.4ms
C. LOOP  (VMIN=1, read(1)x6 loop): 5/5    dt = 603ms   ← (the diag still has +1 target;
                                                          not relevant — the SDK no longer uses this pattern)
D. SDK   (PortHandler.ping): 5/5   result = COMM_SUCCESS, model = 777, dt = 1ms
```

Variant D went from 1208ms / corrupt to **1ms / success**. End-to-end test on `calibrate.py`:

```
Opening /dev/ttyAMA0 at 1000000 baud...
Servo ID to calibrate (1–12): 2
  ✓ Servo 2 online (model 777)
  ID  2  |  Live: 3567  |  >MIN=----  |   MAX=----  |   MID=----
  ✓ MIN = 3567
  ✓ MAX = 797
  ✓ MID = 2402
  Saved → ../config/limits.json
```

STS3215 reported model number **777** in `ping()`. Calibration writes recorded successfully.

---

### Lessons Learned (Phase 5)

1. **`stty -F /dev/ttyAMA0` reporting a baud rate you didn't set is a red flag.** If the kernel says 115200 and your code sets 1Mbps, something else owns the port. Check `/proc/cmdline` for `console=ttyAMA0` / `console=serial0` and `systemctl is-enabled serial-getty@ttyAMA0.service`.

2. **A pyserial loopback test is the cheapest UART sanity check available.** Jumper TX↔RX on the GPIO header. If the Pi can't echo its own bytes, every higher-level theory is wasted effort.

3. **`dmesg | grep -iE "uart|serial|tty"` revealed the answer in three lines.** `console=ttyAMA0,115200` + `serial-getty@ttyAMA0.service` was right there at boot — checking dmesg should be in the first ten things to do when a Pi UART misbehaves, not the last.

4. **Misdiagnoses can be self-confirming.** The Phase 4 "framing error" theory was internally consistent — every observed symptom (0/5/6, never 1–4, retry helps) had a plausible explanation. None of those explanations were right. **The cure for a confirmable theory is a falsifying experiment**: in this case, the loopback test, which collapsed the whole story in one command.

5. **Custom modifications to SDK internals (`port_handler.readPort`) need to be auditable for side effects across all SDK callers, not just the one you're testing.** The `length+1` trick worked for single-transaction reads and broke multi-transaction ones. If you must monkey-patch an SDK, do it at the smallest possible scope (an outer retry wrapper) and leave the inner machinery stock.

6. **On a Pi, `raspi-config → Interface Options → Serial Port` correctly sets BOTH the console and the getty in one step.** Always use it instead of hand-editing `cmdline.txt` and `systemctl disable` separately. Cleaner, harder to get wrong, easier to undo.

7. **Pi Zero 2W gotcha to remember:** the default Ubuntu 24.04 image ships with `console=serial0,115200` in `/boot/firmware/cmdline.txt` AND `serial-getty@ttyAMA0.service` enabled. Either alone breaks high-baud UART; together they're invisible.

---

### Working Configuration as of 2026-05-25

```
Raspberry Pi Zero 2W (Ubuntu 24.04 server)
  GPIO 14 (TX)  ────────────────  TX  ┐
  GPIO 15 (RX)  ────────────────  RX  │  Waveshare Bus Servo Adapter (A)
  GND           ────────────────  GND ┘  (switch: UART-Servo)
                                          │ JST-PH
                                          ▼
                                       STS3215 servo (model 777)

UART:         /dev/ttyAMA0 (PL011)
Baud:         1,000,000
Console:      tty1 only (NOT serial0/ttyAMA0)
getty:        disabled on ttyAMA0 + serial0
SDK:          scservo_sdk (local copy), readPort = stock
Retry layer:  software/control/_serial_utils.py
```

Verified end-to-end: `raw_ping.py`, `ping_one.py`, `sdk_diag.py` (all 5 variants), `calibrate.py` — all working with clean 6/6 responses, sub-millisecond ping times, no retries needed in normal operation.

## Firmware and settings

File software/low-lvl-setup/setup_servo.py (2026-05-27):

#!/usr/bin/env python3
"""
setup_servo.py
--------------
Configure a single STS3215 servo: assign a unique ID, set return delay, and/or
change the baud rate.

Run this script with ONE servo connected to the bus at a time.
All servos ship with factory default ID=1 — if multiple are connected
simultaneously they will collide on the bus and none will respond.

ID, return delay, and baud rate are all EPROM registers — written once, persist
across power cycles. All EPROM writes are done in a single unlock/lock cycle.

Return delay (register 7): delay before servo sends its status packet response.
Unit is 2us per count. Use this to give the host's UART time to switch from
TX to RX direction before the servo response arrives. Recommended: 30 (= 60us).
See docs/debugging/ for the direction-switching timing analysis.

Baud rate (register 6): communication speed. Both Pi and servo must match.
Supported: 1000000, 500000, 250000, 128000, 115200, 57600, 38400, 19200, 9600.
Factory default: 1000000. After changing, power-cycle and use --baud <new_rate>.

--force flag: skips the initial ping and uses broadcast ID (0xFE) for all writes.
Use this when the SDK cannot read a full status packet due to direction-switching
timing issues (i.e. return delay has not been set yet). ONE servo on bus only.

Workflow (repeat for each servo):
  1. Connect one servo to the Waveshare board (power + data)
  2. Run this script with desired options
  3. Wait for confirmation, then unplug that servo
  4. Connect the next servo and repeat

Usage (Pi, run from repo root):
    python3 software/control/setup_servo.py --new-id 2
    python3 software/control/setup_servo.py --new-id 2 --return-delay 30
    python3 software/control/setup_servo.py --current-id 5 --return-delay 30
    python3 software/control/setup_servo.py --current-id 9 --new-baud 250000 --force
    python3 software/control/setup_servo.py --current-id 9 --return-delay 30 --force

ID assignments for hexarm:
    Leader arm:   1, 2, 3, 4, 5, 6   (base -> tip)
    Follower arm: 7, 8, 9, 10, 11, 12 (base -> tip)

Requirements:
    - scservo_sdk present at software/scservo_sdk/ (not a pip package -- local folder)
    - pyserial installed: pip install pyserial
"""

import sys
import os
import argparse

# Local control package — _serial_utils handles VMIN fix + SDK retry wrappers.
sys.path.insert(0, os.path.dirname(__file__))
from _serial_utils import open_sdk_port, ping_with_retry, write_byte_with_retry

# --- register addresses (EPROM) ---
REG_ID           = 5    # Servo ID (0-253; 254 = broadcast)
REG_BAUD         = 6    # Baud rate index (see BAUD_MAP)
REG_RETURN_DELAY = 7    # Return delay time (unit: 2us, range: 0-254, max = 508us)
REG_LOCK         = 55   # EPROM lock (matches scservo_sdk.sms_sts.SMS_STS_LOCK)

# Baud rate register values for STS3215 (register 6)
BAUD_MAP = {
    1_000_000: 0,
      500_000: 1,
      250_000: 2,
      128_000: 3,
      115_200: 4,
       57_600: 5,
       38_400: 6,
       19_200: 7,
        9_600: 8,
}

# --- defaults ---
DEFAULT_PORT       = "/dev/ttyACM0"
DEFAULT_BAUD       = 1_000_000
FACTORY_DEFAULT_ID = 1


def main():
    parser = argparse.ArgumentParser(
        description="Configure ID and return delay on one STS3215 servo.",
        formatter_class=argparse.RawDescriptionHelpFormatter,
        epilog="""
Examples:
  # Assign ID only (no return delay change):
  python3 software/control/setup_servo.py --new-id 2

  # Assign ID and set return delay to 30 units (60us):
  python3 software/control/setup_servo.py --new-id 2 --return-delay 30

  # Set return delay only on a servo already at ID 9:
  python3 software/control/setup_servo.py --current-id 9 --return-delay 30
        """
    )
    parser.add_argument("--new-id",       type=int, default=None,
                        help="New ID to assign (1-253). Omit to keep current ID.")
    parser.add_argument("--current-id",   type=int, default=FACTORY_DEFAULT_ID,
                        help=f"Current ID of servo on bus (default: {FACTORY_DEFAULT_ID})")
    parser.add_argument("--return-delay", type=int, default=None,
                        help="Return delay in 2us units (0-254). 30 = 60us recommended.")
    parser.add_argument("--new-baud",     type=int, default=None,
                        help=f"New baud rate to write to servo EPROM. "
                             f"Supported: {', '.join(str(b) for b in BAUD_MAP)}. "
                             f"Power-cycle servo after changing, then use --baud <new_rate>.")
    parser.add_argument("--port",         default=DEFAULT_PORT,
                        help=f"Serial port (default: {DEFAULT_PORT})")
    parser.add_argument("--baud",         type=int, default=DEFAULT_BAUD,
                        help=f"Baud rate (default: {DEFAULT_BAUD})")
    parser.add_argument("--force",        action="store_true",
                        help="Skip ping verification and use broadcast ID (0xFE) for all writes. "
                             "Use when return delay is not yet set and SDK cannot read status packets. "
                             "ONE servo on bus only.")
    args = parser.parse_args()

    # Resolve target ID (what the servo will be after this script)
    target_id = args.new_id if args.new_id is not None else args.current_id
    change_id = args.new_id is not None and args.new_id != args.current_id

    # Validate
    if args.new_id is not None and not (1 <= args.new_id <= 253):
        print(f"ERROR: --new-id must be 1-253 (got {args.new_id}). 254 is the broadcast address.")
        sys.exit(1)
    if args.return_delay is not None and not (0 <= args.return_delay <= 254):
        print(f"ERROR: --return-delay must be 0-254 (got {args.return_delay}).")
        sys.exit(1)
    if args.new_baud is not None and args.new_baud not in BAUD_MAP:
        print(f"ERROR: --new-baud {args.new_baud} not supported.")
        print(f"  Supported rates: {', '.join(str(b) for b in BAUD_MAP)}")
        sys.exit(1)
    if not change_id and args.return_delay is None and args.new_baud is None:
        print("Nothing to do — specify --new-id, --return-delay, and/or --new-baud.")
        sys.exit(0)

    print(f"\nPort:         {args.port} @ {args.baud} baud")
    print(f"Current ID:   {args.current_id}")
    if change_id:
        print(f"New ID:       {target_id}")
    if args.return_delay is not None:
        print(f"Return delay: {args.return_delay} units = {args.return_delay * 2}us")
    if args.new_baud is not None:
        print(f"New baud:     {args.new_baud} (register value {BAUD_MAP[args.new_baud]})")
    print()

    # --- open port (handles VMIN fix internally) ---
    port_handler, st = open_sdk_port(args.port, args.baud)

    # In --force mode, all writes go to broadcast ID (0xFE).
    # Servo acts on broadcast packets but sends no response — no ACK checking.
    # Use when return delay is not yet set and SDK cannot parse status packets.
    write_id = 0xFE if args.force else args.current_id

    def do_write(label, addr, value):
        """Write one EPROM byte. In broadcast (--force) mode no response is
        expected, so retry is skipped. Otherwise retry with the standard
        framing-error budget. Aborts the script on failure (after re-locking
        EPROM if possible)."""
        print(f"{label} (ID {write_id:#04x})...")
        if args.force:
            # Broadcast — fire and forget; SDK call returns RX_TIMEOUT, ignore.
            st.write1ByteTxRx(write_id, addr, value)
            print(f"  + {label.split('—')[0].strip()} sent (broadcast)")
            return
        ok, result = write_byte_with_retry(st, write_id, addr, value)
        if not ok:
            print(f"  x Write failed: {st.getTxRxResult(result)}")
            # Try to leave EPROM in a sane state before bailing.
            st.LockEprom(write_id)
            port_handler.closePort()
            sys.exit(1)
        print(f"  + {label.split('—')[0].strip()} sent")

    # --- step 1: ping (skipped in --force mode) ---
    if args.force:
        print("Step 1 — Skipping ping (--force mode). Ensure exactly ONE servo is on the bus.")
    else:
        print(f"Step 1 — Pinging ID {args.current_id}...")
        ok, model_number = ping_with_retry(st, args.current_id)

        if not ok:
            print(f"  x No response from ID {args.current_id} after retries.")
            print("\n  Possible causes:")
            print("  - More than one servo connected (ID collision)")
            print("  - Servo already has a different ID -- use --current-id to specify it")
            print("  - Wiring issue or board not powered")
            print("  - Return delay not set yet -- retry with --force to skip ping")
            port_handler.closePort()
            sys.exit(1)

        print(f"  + Servo present -- model: {model_number}")

    # --- step 2: unlock EPROM ---
    do_write("Step 2 — Unlocking EPROM", REG_LOCK, 0)

    # --- step 3a: write new ID (if changing) ---
    if change_id:
        do_write(f"Step 3a — Writing new ID {target_id} to register {REG_ID}",
                 REG_ID, target_id)

    # --- step 3b: write return delay (if requested) ---
    if args.return_delay is not None:
        do_write(f"Step 3b — Writing return delay {args.return_delay} "
                 f"({args.return_delay * 2}us) to register {REG_RETURN_DELAY}",
                 REG_RETURN_DELAY, args.return_delay)

    # --- step 3c: write baud rate (if requested) ---
    if args.new_baud is not None:
        reg_val = BAUD_MAP[args.new_baud]
        do_write(f"Step 3c — Writing baud rate {args.new_baud} "
                 f"(register value {reg_val}) to register {REG_BAUD}",
                 REG_BAUD, reg_val)

    # --- step 4: lock EPROM ---
    do_write("Step 4 — Locking EPROM", REG_LOCK, 1)

    if args.force:
        print(f"\nForce mode -- no verification possible. Power-cycle the servo, then")
        print(f"re-run without --force to confirm settings took effect.")
        if args.new_baud is not None:
            print(f"  Note: servo is now at {args.new_baud} baud. Use --baud {args.new_baud} on next run.")
    else:
        # --- verify: ping the target ID ---
        print(f"\nVerifying -- pinging ID {target_id}...")
        ok, model_number = ping_with_retry(st, target_id)

        if ok:
            print(f"  + SUCCESS -- Servo responds as ID {target_id}")
        else:
            print(f"  x No response on ID {target_id} after retries")

    port_handler.closePort()
    print()


if __name__ == "__main__":
    main()

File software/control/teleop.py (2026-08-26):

#!/usr/bin/env python3
"""
teleop.py — Leader-follower teleoperation.

Leader arm runs torque-free (move it by hand). Follower tracks the leader
in real time at a fixed rate using calibrated normalized positions (0–100).

Startup sequence (handled automatically):
  1. Both arms torque-enabled and moved to the shared neutral pose (the same
     normalized values on both arms — see record_neutral.py/go_neutral.py
     for why this matters: two independently-captured per-arm neutrals are
     never bit-identical, which used to make the follower snap the instant
     leader torque dropped in step 3).
  2. Recorded startup sequence played back on both arms simultaneously,
     then both arms carefully return to neutral (see run_startup_sequence.py
     and set_startup_sequence.py).
  3. Leader torque disabled — move it freely.
  4. Teleop loop starts — follower tracks leader from neutral.

Prerequisites:
  - Both arms calibrated       (software/config/calibration_*.json)
  - Neutral pose captured      (software/config/neutral.json)
  - Startup sequence recorded  (software/config/startup_sequence.json,
    via set_startup_sequence.py)

Usage (from hexarm root, lerobot env):
  source /data/lerobot-env/bin/activate
  python software/control/teleop.py

Ctrl-C to stop. Torque is disabled on exit.
"""

import argparse
import json
import sys
import time
from pathlib import Path

# Add repo root (hexarm/) to path — NOT software/, which would shadow the
# pip-installed scservo_sdk with our local copy and break LeRobot imports.
sys.path.insert(0, str(Path(__file__).resolve().parent.parent.parent))
from software.calibration.go_neutral import go_neutral  # noqa: E402
from software.calibration.run_startup_sequence import run_startup_sequence  # noqa: E402

from lerobot.motors.feetech import FeetechMotorsBus
from lerobot.motors.motors_bus import Motor, MotorCalibration, MotorNormMode

# ── Constants ──────────────────────────────────────────────────────────────────

JOINT_NAMES = [
    "shoulder_pan",
    "shoulder_lift",
    "elbow_flex",
    "wrist_flex",
    "wrist_roll",
    "gripper",
]

FOLLOWER_NAMES = [f"follower_{j}" for j in JOINT_NAMES]
LEADER_NAMES   = [f"leader_{j}"   for j in JOINT_NAMES]

CONFIG_DIR   = Path("software/config")
DEFAULT_PORT = "/dev/ttyACM0"
DEFAULT_HZ   = 50

# ── Helpers ────────────────────────────────────────────────────────────────────

def load_json(path: Path) -> dict:
    if not path.exists():
        raise FileNotFoundError(f"Missing config file: {path}")
    with open(path) as f:
        return json.load(f)


def build_bus(port: str, cal_follower: dict, cal_leader: dict) -> FeetechMotorsBus:
    """
    Construct a single FeetechMotorsBus containing all 12 motors.

    Both arms share one physical bus (/dev/ttyACM0). Motor names are prefixed
    (follower_shoulder_pan, leader_shoulder_pan, ...) so both arms can live in
    the same dict without name collisions.

    Follower IDs: 1–6   (joints 1–6 in order)
    Leader IDs:   7–12  (same joints, +6 offset)
    """
    motors: dict[str, Motor] = {}
    for i, joint in enumerate(JOINT_NAMES):
        motors[f"follower_{joint}"] = Motor(
            id=i + 1,
            model="sts3215",
            norm_mode=MotorNormMode.RANGE_0_100,
        )
        motors[f"leader_{joint}"] = Motor(
            id=i + 7,
            model="sts3215",
            norm_mode=MotorNormMode.RANGE_0_100,
        )

    calibration: dict[str, MotorCalibration] = {}
    for joint, data in cal_follower.items():
        calibration[f"follower_{joint}"] = MotorCalibration(**data)
    for joint, data in cal_leader.items():
        calibration[f"leader_{joint}"] = MotorCalibration(**data)

    return FeetechMotorsBus(port=port, motors=motors, calibration=calibration)


def safe_enable_torque(bus: FeetechMotorsBus, motor_names: list[str]) -> None:
    """
    Enable torque on the named motors without a snap-to-stale-goal.

    Reads each motor's current position and writes it as the Goal_Position
    before enabling torque. This freezes the motor in place on engage.
    """
    for name in motor_names:
        pos = bus.read("Present_Position", name, normalize=False, num_retry=3)
        bus.write("Goal_Position", name, int(float(pos)), normalize=False, num_retry=3)
    bus.enable_torque(motors=motor_names)


# ── Teleop loop ────────────────────────────────────────────────────────────────

def run_teleop(bus: FeetechMotorsBus, hz: int = DEFAULT_HZ) -> None:
    """Stream leader joint positions to the follower arm at `hz` Hz."""
    period = 1.0 / hz
    print(f"Teleop running at {hz} Hz.  Ctrl-C to stop.\n")

    while True:
        t0 = time.monotonic()

        # Read all 6 leader joint positions in one SYNC_READ transaction.
        # normalize=True applies calibration + drive_mode → values in 0–100.
        leader_pos = bus.sync_read("Present_Position", motors=LEADER_NAMES, normalize=True)

        # Map leader joint names → follower joint names (1:1 normalized).
        # drive_mode in calibration handles any physical direction inversions.
        follower_goals = {
            f"follower_{joint}": leader_pos[f"leader_{joint}"]
            for joint in JOINT_NAMES
        }

        # Send all 6 follower goals in one SYNC_WRITE transaction.
        bus.sync_write("Goal_Position", follower_goals, normalize=True)

        elapsed = time.monotonic() - t0
        time.sleep(max(0.0, period - elapsed))


# ── Main ───────────────────────────────────────────────────────────────────────
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

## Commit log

2026-05-07 Add project context documentation to encapsulate current project state
2026-05-11 add teleop.py (read from servoes), calibrate.py(allows limits to be recorded), and limits.json (limit storage)
2026-05-11 fixed missing Motors class in config.py
2026-05-11 updated Motor class in config.py
2026-05-16 added open source st3215 control files
    [sts3215_memory_table.xlsx]
2026-05-17 moved all arduino-related files and directories into the software/arduino folder, which I will likely NOT be using for this project
    [sts3215_memory_table.xlsx]
2026-05-17 Added STServo Python libraries, attempted to debug servoes by creating various scripts to no avail
2026-05-17 actually pushed all files; last push was done above root accidentally
    [pyvenv.cfg]
2026-05-20 committed a bunch of files in a desperate attempt to get the servo to respond after 16 glorious hours of fruitful debugging
    [sts3215_memory_table.xlsx]
2026-05-20 fix default ports for Pi UART, add scservo_sdk
    [baud_scan.py, ping_one.py, raw_ping.py]
2026-05-20 docs: record servo comms breakthrough and update Pi setup
    - Add servo-comms-debug-log.md: full 3-day debugging narrative,
    root cause (Waveshare non-standard TX→TX/RX→RX wiring), and
    lessons learned
    - Update context.md: Pi SSH info, resolved servo comms status,
    correct wiring diagram, Pi UART config commands, learning log
    - Update default ports in ping_one.py, raw_ping.py, baud_scan.py
    from Mac USB to Pi UART (/dev/ttyAMA0, 1Mbps, ID=1)
2026-05-20 Add servo ID assignment script and rewrite calibration
    - Copy scservo_sdk to software/scservo_sdk/ (fixes import path for all control scripts)
    - Add software/control/assign_id.py: CLI tool to flash unique IDs to servos one at a time.
    Sequence: ping current ID -> unlock EPROM -> write new ID -> lock EPROM -> verify ping.
    - Rewrite software/control/calibrate.py: remove LeRobot dependency, use scservo_sdk directly.
    Supports --arm leader/follower, pings all servos first, disables torque, saves limits.json.
    [calibrate.py, port_handler.py, sms_sts.py]
2026-05-20 Replace assign_id.py with setup_servo.py
    - Delete assign_id.py
    - Add setup_servo.py: configures servo ID and/or return delay in one EPROM
    unlock/lock cycle. Return delay (reg 7, 2us/unit) added to fix Waveshare
    board direction-switching timing — servo response was arriving before host
    RX was ready, causing partial reads. Recommended: --return-delay 30 (60us).
    [setup_servo.py]
2026-05-20 Add setup_servo.py, update .gitignore
    - Add ~$* to .gitignore to exclude Office temp/lock files
    - Add software/control/setup_servo.py: replaces assign_id.py, adds --return-delay
    parameter (register 7, 2us/unit) to fix Waveshare board direction-switching issue
    - Delete software/control/assign_id.py (superseded)
2026-05-20 Add --force flag to setup_servo.py
    Skips ping and uses broadcast ID (0xFE) for EPROM writes when SDK cannot
    read status packets due to direction-switching timing issue (return delay
    not yet set). No ACK checking in force mode — one servo on bus only.
    [setup_servo.py]
2026-05-20 Add read_register.py — raw pyserial script to read any servo register
    Bypasses SDK entirely. Useful for verifying EPROM writes (e.g. return delay,
    ID) when SDK cannot parse status packets due to direction-switching timing.
2026-05-20 Fix VMIN=1 byte-by-byte read issue on ttyAMA0
    - raw_ping.py: rewrite to read response one byte at a time with timeout,
    parse and validate full 6-byte status packet, remove ser.flush()
    - scservo_sdk/port_handler.py: patch readPort() to loop on read(1) instead
    of calling read(n) which returns after 1 byte due to VMIN=1 on ttyAMA0.
    Root cause: Pi PL011 UART tty configured with VMIN=1 VTIME=0 by default.
    [port_handler.py, raw_ping.py]
2026-05-20 Fix raw_ping.py: set VMIN via termios after port open
    pyserial sets VMIN=0 VTIME=0 on open and settings persist after close,
    causing read() to return 0 bytes on subsequent runs. Fix by explicitly
    setting VMIN=6 after open so read(6) blocks until full response arrives.
    [raw_ping.py]
2026-05-20 chore: remove STServo_Python venv and LeRobot stubs
    - Delete software/STServo_Python/ — Windows venv with full STServo SDK.
    Redundant since scservo_sdk is vendored at software/scservo_sdk/.
    - Delete software/control/bus.py and teleop.py — LeRobot-dependent stubs,
    non-functional on Pi Zero 2W without full LeRobot install. teleop.py
    will be rewritten from scratch against scservo_sdk when needed.
    [pyvenv.cfg]
2026-05-20 Add ping_stress.py — serial stress-test diagnostic for intermittent response pattern
2026-05-20 send over diagnostic test csv output files
    [keepopen.csv, reopen.csv]
2026-05-21 Add resync parser + retry to raw_ping.py and port_handler.py
    - raw_ping.py: resync parser accepts 5-byte responses missing the leading
    0xFF (framing error at bus turnaround); retries up to 2x on empty response
    - port_handler.py: readPort reads length+1 bytes, resyncs to FF FF header,
    reconstructs packet if first 0xFF was silently dropped by Linux tty layer
    - setup_servo.py: add --new-baud option to write baud rate EPROM register
    [port_handler.py, raw_ping.py]
2026-05-21 docs: update context.md and debug log with 2026-05-20 session findings
    - Servo comms section: add Issue 2 (framing error, VMIN, resync parser)
    - Setup status: all 12 IDs assigned, framing fix done, new todo items
    - Repo structure: remove deleted files, add setup_servo.py and ping_stress.py
    - Concepts: add framing error, IGNPAR, VMIN, RC transient, EPROM workflow
    - Debug log Phase 4: full narrative of 0/5/6 investigation and fix
    - Debug log: servo ID assignment table and --force mode caveats
2026-05-21 rewrite calibrate.py: interactive tab/enter UI, live position display, MIN/MAX/MID slots, readchar
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2026-05-21 port_handler: fix timeout=0 O_NONBLOCK issue; calibrate: VMIN fix, retry logic
    [port_handler.py]
2026-05-25 port_handler: revert readPort to SDK original
    The custom resync/reconstruction loop was working around getty interference
    on /dev/ttyAMA0, not a real framing error. With the serial console removed
    the bus returns clean 6/6 every time. The length+1 read pattern also broke
    multi-transaction SDK calls (ping does PING + read-model) by stealing the
    last byte of the response on the first read. Reverting to ser.read(length)
    restores correctness for multi-transaction calls.
    [port_handler.py, sdk_diag.py]
2026-05-25 Document Phase 5 root cause; revert port_handler.readPort; update context/README; gitignore CSV diagnostics
    [_serial_utils.py]
2026-05-27 chore: update default serial port to /dev/ttyACM0 (Jetson USB)
    All control scripts previously defaulted to /dev/ttyAMA0 (Pi UART).
    Updated to /dev/ttyACM0 — confirmed working port on Jetson Orin Nano
    Super via cdc_acm driver (Waveshare board in USB-Servo mode).
2026-05-27 renamed old control file to setup, created file for moving servoes
    [keepopen.csv, reopen.csv]
2026-05-28 wrote ~half of move_one.py; almost finished servo ID loop with readchar and nested while loops
2026-05-28 created torque_off.py after the great pinky squishing of '26
2026-05-31 added keyboard_follower.py - control follower arm using keyboard commands
2026-05-31 created calibrate_lerobot - manually sweep robot's joints to limits, this script records and formats their limits
2026-05-31 ran calibrate_lerobot, generated calibration_follower.json limits file
2026-05-31 added input arguments to calibrate_lerobot.py
2026-05-31 debug calibrate script to halt tweakage
2026-06-01 Rewrote context.md, slight changes to calibrate_lerobot and keyboard_follower files. Changed AI-driven learning approach to promote more active problem solving
    [calibrate_lerobot.py]
2026-06-01 added bus.calibrate() to clear phase bit (was causing overflow when motors moved past their arbitrary seam point)
2026-06-01 calibrated joints 1-5 of leader
2026-06-01 fixed json overwrite upon joint skip
    [calibrate_lerobot.py]
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2026-06-02 added calibration + neutral json files for leader
2026-06-02 restructured repo within software
    [keepopen.csv, reopen.csv]
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2026-06-02 update go_neutral.py and monitor_joints.py to use Maximum_Velocity_Limit for joint control
2026-06-02 update go_neutral.py to replace duration argument with velocity and acceleration for joint control
    [go_neutral.py]
2026-06-02 refactor go_neutral.py to stop upon +/- of target position instead of velocity
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2026-06-03 refactor: update sys.path to include repo root for correct imports
    [teleop.py]
2026-06-03 increased polling from 20 to 50 hz in teleop.py to fix lagginess
    [go_neutral.py, teleop.py]
2026-07-15 updated scripts and documentation to properly reflect current project state
2026-07-22 parameterized config scripts to allow for easier calibration
2026-07-27 docs: mark recalibration/angle-limits done, log claw redesign, add personal session guide
    - README/context.md: clean re-calibration and EPROM angle limits confirmed done (2026-07-27)
    - postmortems.md: add #5 (claw too small, dropping objects) alongside #4 (leader actuation force) as the two open threads driving a claw redesign
    - context.md: log modular-vs-monolithic CAD design as an in-progress lesson from that redesign
    - docs/session.md: new personal fast-path doc (setup checklist + living where-we-left-off log), including camera-placement research for the incoming overhead cam
    - fix stale path in record_neutral.py docstring
2026-08-03 Add startup sequence feature, fix neutral-pose snap bug, move torque_off to control
    - record_neutral.py/go_neutral.py: drop --arm flag, always capture/drive a
    single shared neutral.json for both arms instead of two independently
    hand-posed captures. Fixes follower snapping to the leader's position the
    instant leader torque dropped at teleop startup (two hand-poses were never
    bit-identical).
    - set_startup_sequence.py / run_startup_sequence.py: record and replay a
    hand-performed leader-arm motion (neutral -> sequence -> neutral) on both
    arms; teleop.py now runs this at startup instead of a bare go_neutral().
    - calibrate_lerobot.py: drop redundant Enter prompt before
    record_ranges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
    [calibrate_lerobot.py, go_neutral.py, teleop.py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]
2026-08-04 Harden startup sequence, re-calibrate follower after joint reprint, add dataset recording script
    - go_neutral.py: at_neutral() pre-check, --diagnostic hold-to-move mode, fix strict-< arrival tolerance bug (0.5 -> 1.0, <=)
    - set_startup_sequence.py: drive both arms to neutral before recording, drop leader torque only, extend recording window 5s -> 10s
    - Re-calibrate follower (elbow_flex reprinted/reassembled) and recapture neutral.json/startup_sequence.json
    - Add record_dataset.py: single-bus teleop tick + camera capture into a LeRobotDataset, working around lerobot-record's two-port assumption
    [go_neutral.py, record_dataset.py]
2026-08-05 docs: log JetPack 7.2 reflash session, resolve CH343 serial "blocker"
    Jetson reflashed 6.2 -> 7.2 for LeRobot's Python 3.12 requirement
    (cp312 CUDA torch only exists for JP7.2). New env is a venv at
    /data/lerobot-env; torch 2.12.0 + CUDA verified working.
    The CH343 USB-serial bridge was flagged mid-reflash as needing an
    out-of-tree driver, but journalctl showed cdc_acm already claims it
    as /dev/ttyACM0 -- same as before the reflash, zero driver work
    needed. Confirmed via FeetechMotorsBus.broadcast_ping() returning
    all 12 servo IDs.
2026-08-09 Finalize CAD assembly for both arms, add STEP exports and renders
    Full CAD assembly (leader + follower) completed in Onshape, closing out
    the M1 milestone. Two build issues surfaced during assembly and were
    resolved (postmortems #6 base stability, #7 servo-mount joint bending).
    STEP exports of both arms' custom parts added under cad/exports/,
    trimmed from Onshape's raw 111MB/66-file per-part export down to 6.5MB
    by dropping STL and 11 redundant duplicate copies of the vendor servo
    model. Assembly renders added under cad/renders/ and wired into the
    README Demo section.
    [arducam_b0385.step, base.step, bottom_rack.step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]
2026-08-10 added overhead camera cad files
    [Claw Pad.step, Overhead Cam Mount - Base.step, Overhead Cam Mount - Extension.step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]
2026-08-10 docs: close out wrist camera verification, update record_dataset.py usage docs
    Wrist camera placement confirmed good (2026-08-05), closing the last
    item blocking dataset recording; both cameras now wired into
    record_dataset.py's OpenCVCamera config. Adds record_dataset.py CLI
    param docs and switches its usage example to the venv activation
    path. Drops the stale lerobot.code-workspace (now gitignored).
2026-08-10 Fix dataset recording crashes, add retry margin, cut encode time ~3.4x
    record_dataset.py fixes from the first real recording session:
    - image_writer_threads now scales with camera count (was shared across
    both cameras at 4 total vs LeRobot's own "4 per camera" guidance,
    causing save_episode() to silently stall draining the backlog)
    - --resume was broken (LeRobotDataset.resume() requires an explicit
    root, unlike create(); now passes HF_LEROBOT_HOME/repo_id)
    - frames are resized to 640x400 (same aspect ratio as the native
    1280x800 capture) before being written/encoded — measured ~3.4x
    faster PNG writes + video encode, since policies downsample anyway
    - arms now return to neutral af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
    [calibrate_lerobot.py, go_neutral.py, record_dataset.py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]
2026-08-10 Fix record_dataset.py writing frames at the wrong resolution on --resume
    The 640x400 recording size only applies at dataset creation
    (build_dataset_features()); --resume loads an existing dataset's
    already-locked schema and never touches that path. Resuming
    hexarm/pick_and_place (created at 1280x800 before this recording size
    existed) fed 640x400 frames into a dataset still declared at 1280x800.
    LeRobot's writer advances its episode counter before the mismatched
    video merge actually fails, so this produced two uncommitted "phantom"
    episodes: meta/info.json claimed 5 episodes/3447 frames while the real
    parquet/video data only ever had 3/2268 — silent data loss with no
    error surfaced.
    Fix: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
    [record_dataset.py]
2026-08-11 Session 12: dataset recording complete (50 episodes), doc updates
    All 50 target episodes recorded into hexarm/pick_and_place_v2 (640x400
    @30fps), verified structurally sound and visually reviewed. Updates
    README, context.md, and session.md to reflect this, add a session-12
    log entry covering the record_dataset.py hardening work (neutral-return
    timing, image-writer thread starvation, num_retry, --resume root
    inference, resolution/speed fix) and the Jetson-vs-cloud training-time
    research. Adds postmortems.md #8 for the phantom-episode data-loss
    incident caused by the resolution fix interacting with --resume on the
    older pick_and_place dataset.
    Also includes a leftover DEFAULT_RESET_SECONDS 10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
    [record_dataset.py]
2026-08-18 feat: complete policy training and implement run_policy script
    - Updated README.md to reflect the completion of policy training (25,000 steps) and the successful evaluation of checkpoints, confirming the best model.
    - Added new documentation files for component specifications, including camera datasheets and communication manuals.
    - Enhanced context.md with detailed updates on training progress, including the resolution of RAM exhaustion issues on the Jetson and the decision to run training locally.
    - Documented the root cause and fix for Jetson hard-freezes during training in postmortems.md.
    - Created run_policy.py to execute the trained policy on the follower arm, implementing a dead-man's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
    [sts3215_memory_table.xlsx]
2026-08-20 docs: add LICENSE and hardware assembly guide, prune stale/personal docs
    Adds the missing MIT LICENSE file (README linked to it already) and a new
    hardware-assembly-guide.md covering fasteners, 3D printing settings, build
    order, and the workspace/clamping constraints that matter for data
    collection. Removes session.md, robotdogplan.md, kinematics.md, the stale
    Pi 5 pinout image, and the superseded Arduino baud-rate sketch, and fixes
    every reference to them across the README and docs/context.md - two pieces
    of content unique to session.md (camera-placement research, the two-venv
    rule of thumb) were folded into context.md rather than lost. Also trims
    the README's status blurb and fixes its set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
2026-08-23 docs: portfolio polish — pin LeRobot version, README badges, context.md summary/TOC
    Adds requirements.txt pinning the exact LeRobot build (base commit +
    docs/jetson-jp7.2-local.patch for the unpublished local patch that
    widens torch/torchvision bounds for the Jetson wheel), MIT/Python
    badges on the README, and a summary + linked TOC at the top of
    docs/context.md so it's navigable as a portfolio-facing doc.
2026-08-25 Update README with new JetPack and hardware details
    Updated JetPack version and Ubuntu OS in the README. Added details about reach and payload specifications. Clarified power supply requirements and setup instructions.
2026-08-25 Update documentation on servo topology and data handling
    Clarified the explanation of shared neutral pose and updated the description of data transactions for both arms. Removed fallback mention for the second Waveshare board.
2026-08-25 Prepare repo for public release: tense/voice pass across docs, remove vendored duplicates and stale artifacts, fix a live crash bug in monitor_joints.py
    [keepopen.csv, reopen.csv, sts3215_memory_table.xlsx]
